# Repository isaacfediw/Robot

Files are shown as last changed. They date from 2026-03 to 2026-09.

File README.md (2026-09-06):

# Robot
A robot I am building that will follow you around

## Modes
### Auto Mode
**Overview**  
In auto mode the robot is designed to track the position of the transmitter and go to it.  
The DWM3000 can provide highly accurate and precise measurements when done correctly. The  
method I used for finding the distance between the robot (receiver) and the transmitter is known as  
double-sided two-way ranging. After calculating the distance I apply a lowpass fir filter to it using  
a hamming window with 31 taps. Once the distance is calculated the robot pivots itself slightly to the  
left and measures the distance again. It takes note of when the distance is incrementing. If the distance  
starts to decrement after it has already been noticed to increment the robot knows that the position before  
the last slight left pivot must be when the receiver antenna is angled farthest away from the transmitter  
antenna. This works because the receiver antenna is mounted near the end of the robot chassis.  



The problem with my current setup is that my distance measurements are not precise nor accurate when the  
receiver is mounted on the robot chassis. This is because the DWM3000 antennas are vertically polarized,  
which means they will communicate with the lowest amount of noise when they are both on the XZ plane.  
Although slightly more noisy (with introduced nulls), if both antenna are positioned on the XY plane,  
perpendicular to each other, the measurements are still relatively accurate and precise. For the time  
being (while in their respective chassis), the transmitter antenna is positioned on the XY plane and the  
receiver antenna is positioned on the YZ plane. This makes the measurements significantly inaccurate and  
imprecise, preventing auto mode from correctly working. My hope is to redesign the robot chassis to   
support ideally an antenna which is positioned on the XY plane but at the least on a 45 degree angle  
between the XY and YZ planes.  

**How double-sided two-way ranging works**  
6 timestamps are measured: t1 (measured when the transmitter  
sends the first frame), t2 (measured when the receiver receives that first frame), t3  
(measured when the receiver sends its first response), t4 (measured when the transmitter  
receives the receiver's first response), t5 (measured when the transmitter sends the second  
frame), and t6 (measured when the receiver receives that second frame).  

From the 6 timestamps, 4 time values are calculated. The round trip time for the first frame,  
the round trip time for the second frame, the reply time for the first frame, and the reply  
time for the second frame. The time of flight (tof) then calculated as:  
(round trip 1 * round trip 2 - reply 1 * reply 2) / (round trip 1 + round trip 2 + reply 1 + reply 2)  

<details> 
  <summary> For the proof on why the tof equation works click here </summary>

### DS-TWR Time-of-Flight Derivation
#### 1. Numerator Expansion:
$$
\begin{aligned}
\mathrm{tof\_num} &= R_1 R_2 - D_1 D_2 \\
&= (2T + D_1)(2T + D_2) - D_1 D_2 \\
&= 4T^2 + 2T D_2 + 2T D_1 + D_1 D_2 - D_1 D_2 \\
&= 4T^2 + 2T(D_1 + D_2) \\
&= 2T(2T + D_1 + D_2)
\end{aligned}
$$

#### 2. Denominator Expansion:
$$
\begin{aligned}
\mathrm{tof\_denom} &= R_1 + R_2 + D_1 + D_2 \\
&= (2T + D_1) + (2T + D_2) + D_1 + D_2 \\
&= 4T + 2D_1 + 2D_2 \\
&= 2(2T + D_1 + D_2)
\end{aligned}
$$

#### 3. Final Division and Cancellation:
$$
\begin{aligned}
\text{tof} &= \frac{\mathrm{tof\_num}}{\mathrm{tof\_denom}} \\
&= \frac{2T(2T + D_1 + D_2)}{2(2T + D_1 + D_2)} \\
&= \frac{2T}{2} \\
&= T
\end{aligned}
$$

</details>

We then multiply the time of flight by 15.65E-12 to get from DWT system time to seconds.  
Finally, to calculate the distance (in cm) the tof in seconds is multiplied by 100 times  
times the speed of light.  

### Manual Mode
**Overview**  
In manual mode the user has full control over the robot by using the joystick on the transmitter.  
The RP2040-Zero features a 12 bit adc, but I limit the range to 0 to 800 and then shift it by  
540 to make the rest position 0, the low position -240, and the highest position +260, in both  
x and y directions. I implemented a software deadzone of 50 adc values to prevent unwanted drifting  
when in manual mode.  
  
**How the direction and speed is decided**  
I compare the x and y adc value. If x > y then we want to turn the robot, otherwise we want to move  
forward or backward. If we are turning and x > 0 we want to go left, otherwise we go right. If we are  
not turning and y > 0 we want to go forwards, otherwise we go backwards. The amount of steps we want the  
robot to take is calculated by mapping the adc value to a steps value, using -240 and +260 as the adc range    
and 10 and 100 as the step range. This information is then sent to the robot in 3 bytes. (0xAB to indicate  
manual mode, a direction byte, and the number of steps as the final byte).  



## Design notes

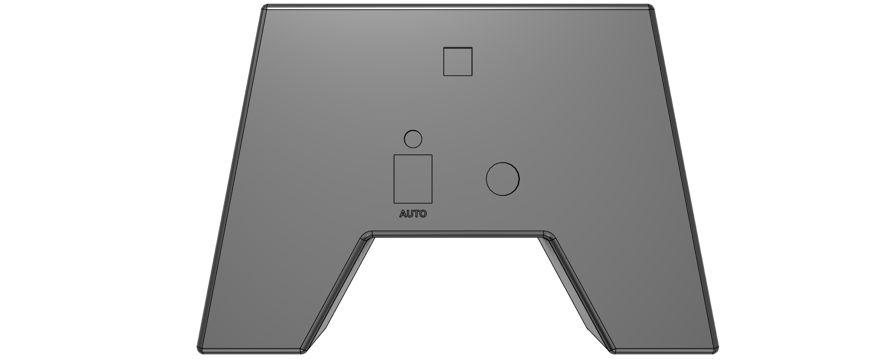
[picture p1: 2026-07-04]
Transmitter Schematic/Transmitter.png

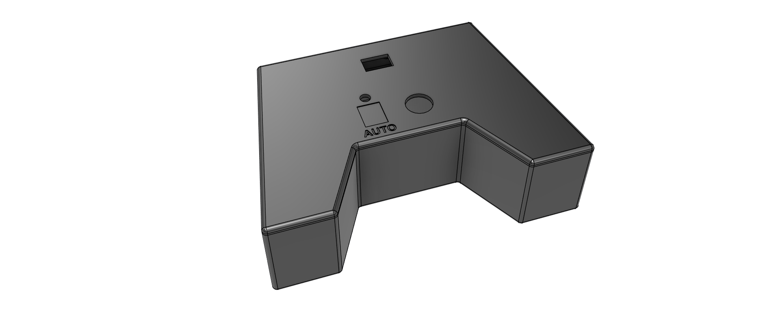
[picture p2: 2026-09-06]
3D Models/Transmitter/Transmitter 3D Model Image.png

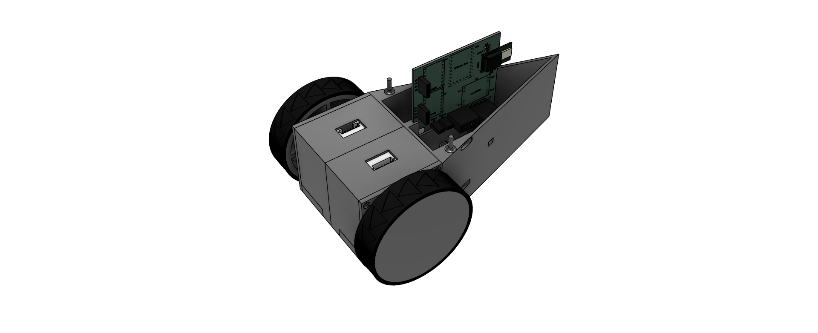
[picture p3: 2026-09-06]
3D Models/Robot/Robot 3D Model Image.png

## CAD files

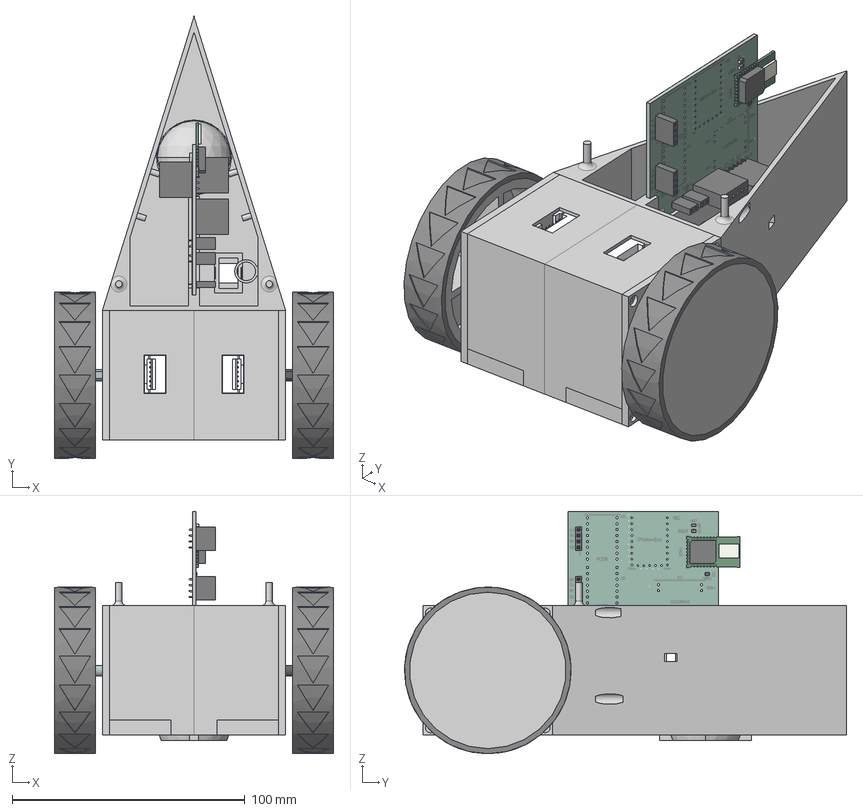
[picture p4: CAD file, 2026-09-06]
3D Models/Robot/Robot.step
120.0 x 190.0 x 104.2 mm
NEMA 17 (Check wire connector dimensions as well as shaft dimensions
Robot Left
Robot Right
NEMA 17 (Check wire connector dimensions as well as shaft dimensions( Mirror)
PinSocket_1x04_P2.54mm_Vertical x 2
C_0805_2012Metric x 2
R_0805_2012Metric
PinSocket_1x06_P2.54mm_Vertical x 2
DWM1000
PinSocket_1x02_P2.54mm_Vertical x 2
Robot_silkscreen
Robot_soldermask
Robot_soldermask_1
Robot_PCB
PinSocket_1x06_P2.54mm_Vertical_1

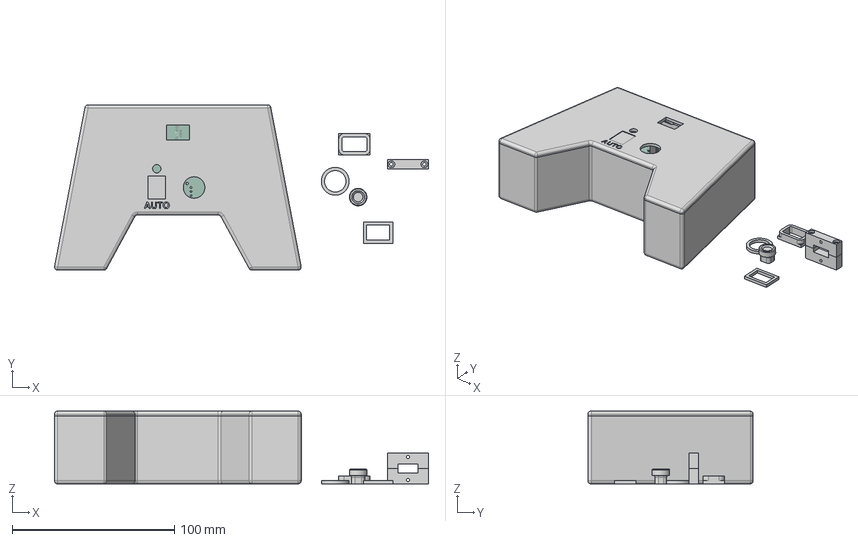
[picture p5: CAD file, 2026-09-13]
3D Models/Transmitter/Transmitter.step
230.6 x 102.0 x 45.0 mm
C_0805_2012Metric x 2
PinSocket_1x02_P2.54mm_Vertical x 4
R_0805_2012Metric x 2
PinSocket_1x03_P2.54mm_Vertical
DWM1000
Transmitter_silkscreen
Transmitter_soldermask
Transmitter_soldermask_1
Transmitter_PCB

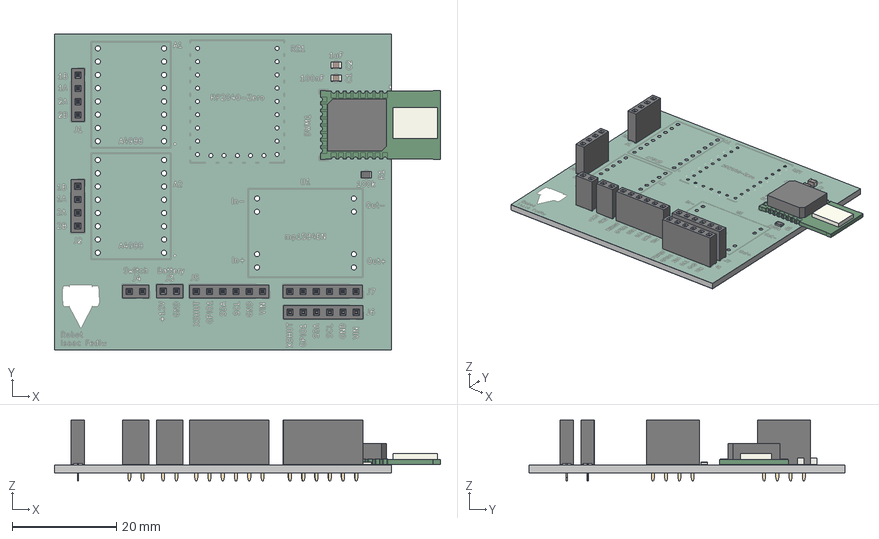
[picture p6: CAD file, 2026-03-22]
Robot Schematic/Robot PCB.step
73.9 x 60.6 x 11.6 mm
PinSocket_1x04_P2.54mm_Vertical x 2
C_0805_2012Metric x 2
R_0805_2012Metric
PinSocket_1x06_P2.54mm_Vertical x 3
DWM1000
PinSocket_1x02_P2.54mm_Vertical x 2
Robot_silkscreen
Robot_soldermask x 2
Robot_PCB

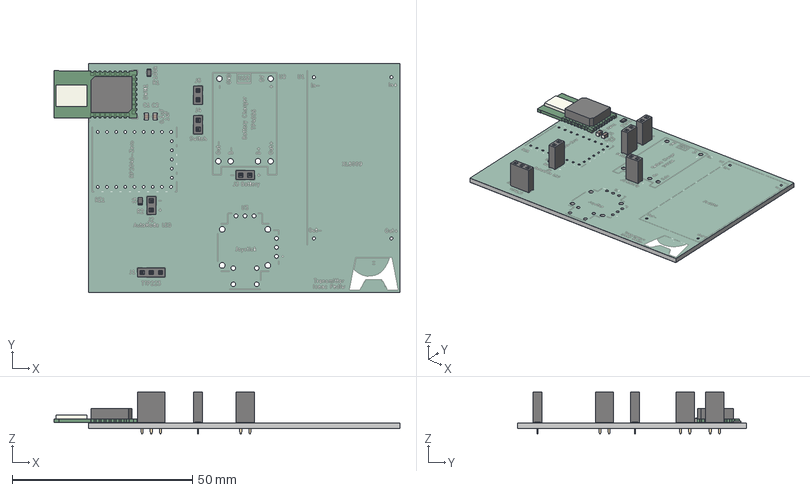
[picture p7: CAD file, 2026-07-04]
Transmitter Schematic/Transmitter.step
96.0 x 63.5 x 11.6 mm
C_0805_2012Metric x 2
PinSocket_1x02_P2.54mm_Vertical x 4
R_0805_2012Metric x 2
PinSocket_1x03_P2.54mm_Vertical
DWM1000
Transmitter_silkscreen
Transmitter_soldermask x 2
Transmitter_PCB

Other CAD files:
3D Models/Robot/Robot.3mf
3D Models/Transmitter/Transmitter.3mf

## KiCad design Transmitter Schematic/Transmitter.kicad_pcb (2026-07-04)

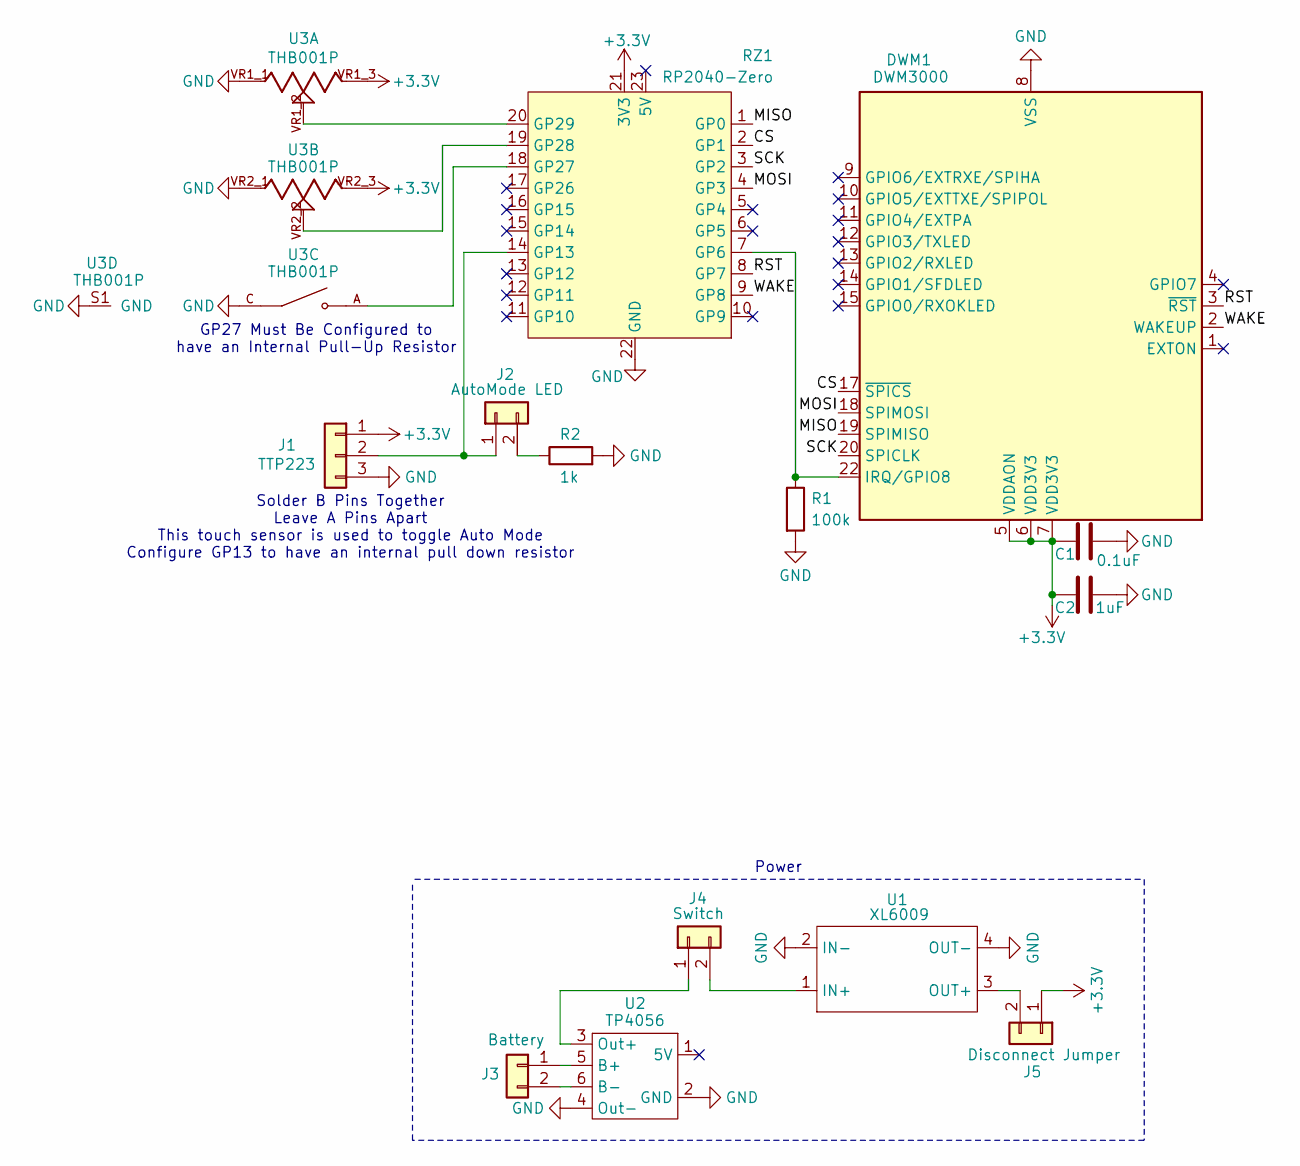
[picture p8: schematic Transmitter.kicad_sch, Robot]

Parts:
C1: 0.1uF; C_0805_2012Metric
C2: 1uF; C_0805_2012Metric
DWM1: DWM3000; DWM1000; MPN DWM3000.E1.1SR
J1: TTP223; PinSocket_1x03_P2.54mm_Vertical
J2: AutoMode LED; PinSocket_1x02_P2.54mm_Vertical
J3: Battery; PinSocket_1x02_P2.54mm_Vertical
J4: Switch; PinSocket_1x02_P2.54mm_Vertical
J5: Disconnect Jumper; PinSocket_1x02_P2.54mm_Vertical
R1: 100k; R_0805_2012Metric_Pad1.20x1.40mm_HandSolder
R2: 1k; R_0805_2012Metric_Pad1.20x1.40mm_HandSolder
RZ1: RP2040-Zero
U1: XL6009
U2: TP4056; TP4056-18650
U3: THB001P; CNK_THB001P; PARTREV 27 Jan 22

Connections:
+3.3V: C1.1, C2.1, DWM1.5 (VDDAON), DWM1.6 (VDD3V3), DWM1.7 (VDD3V3), J1.1, J5.1, RZ1.21 (3V3), U3.VR1_3, U3.VR2_3
/CS: DWM1.17 (~SPICS), RZ1.2 (GP1)
/MISO: DWM1.19 (SPIMISO), RZ1.1 (GP0)
/MOSI: DWM1.18 (SPIMOSI), RZ1.4 (GP3)
/RST: DWM1.3 (~RST), RZ1.8 (GP7)
/SCK: DWM1.20 (SPICLK), RZ1.3 (GP2)
/WAKE: DWM1.2 (WAKEUP), RZ1.9 (GP8)
GND: C1.2, C2.2, DWM1.8 (VSS), DWM1.16 (VSS), DWM1.21 (VSS), DWM1.23 (VSS), DWM1.24 (VSS), J1.3, R1.2, R2.2, RZ1.22 (GND), U1.2 (IN-), U1.4 (OUT-), U2.2 (GND), U2.4 (Out-), U3.C, U3.D, U3.S1 (GND), U3.S2, U3.S3, U3.S4, U3.VR1_1, U3.VR2_1
unnamed: DWM1.22 (IRQ/GPIO8), R1.1, RZ1.7 (GP6)
unnamed: J1.2, J2.1, RZ1.14 (GP13)
unnamed: J2.2, R2.1
unnamed: J3.1, U2.5 (B+)
unnamed: J3.2, U2.6 (B-)
unnamed: J4.1, U2.3 (Out+)
unnamed: J4.2, U1.1 (IN+)
unnamed: J5.2, U1.3 (OUT+)
unnamed: RZ1.18 (GP27), U3.A, U3.B
unnamed: RZ1.19 (GP28), U3.VR2_2
unnamed: RZ1.20 (GP29), U3.VR1_2

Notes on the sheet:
GP27 Must Be Configured to have an Internal Pull-Up Resistor
Power
Solder B Pins Together Leave A Pins Apart This touch sensor is used to toggle Auto Mode Configure GP13 to have an internal pull down resistor

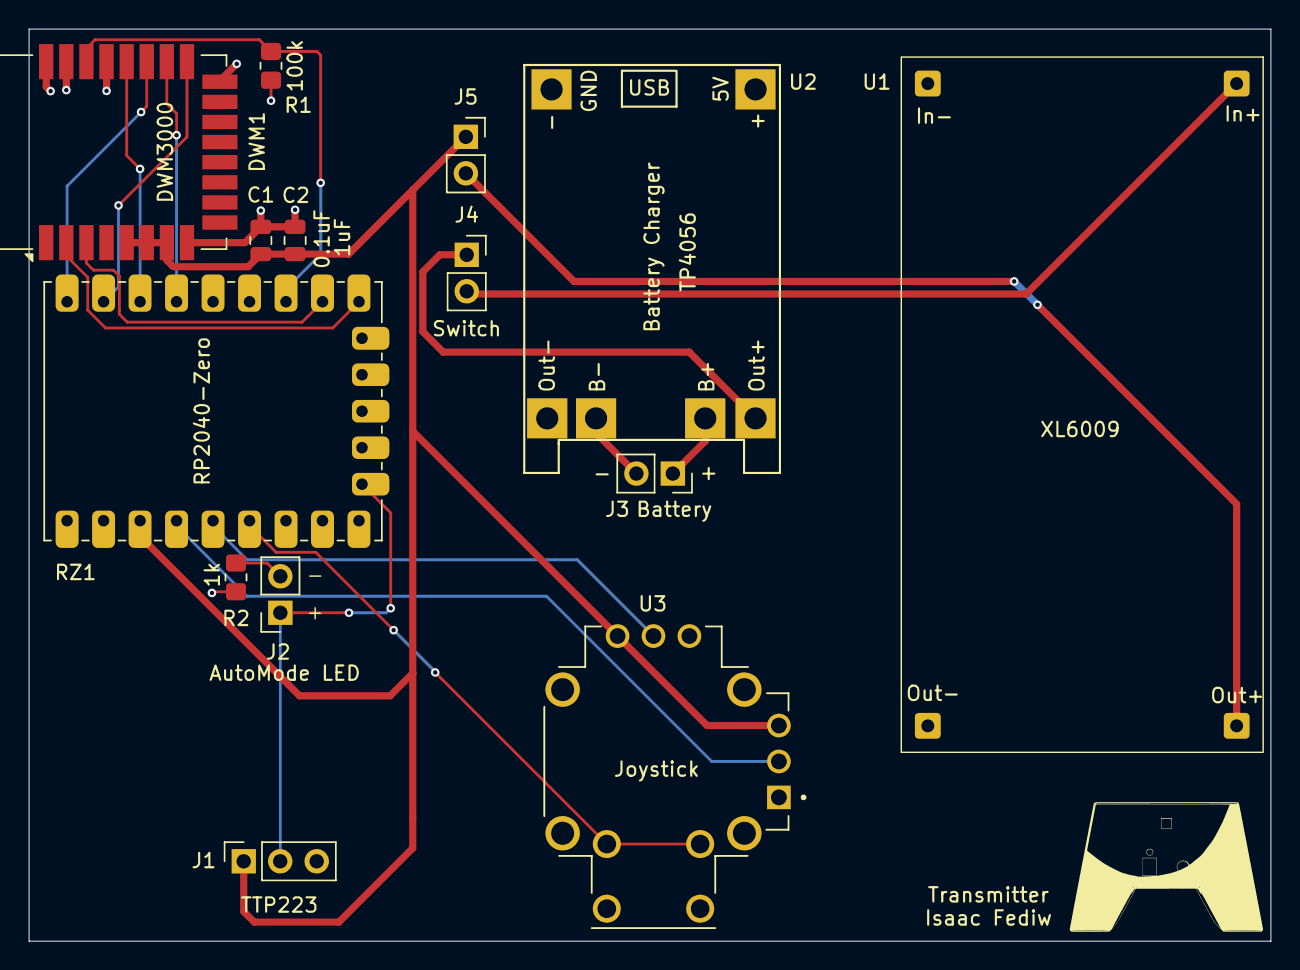
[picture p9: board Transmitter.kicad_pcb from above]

Board: 2 copper layers, 86.4 x 63.5 mm, 14 parts (0 on the bottom side), 19 nets.

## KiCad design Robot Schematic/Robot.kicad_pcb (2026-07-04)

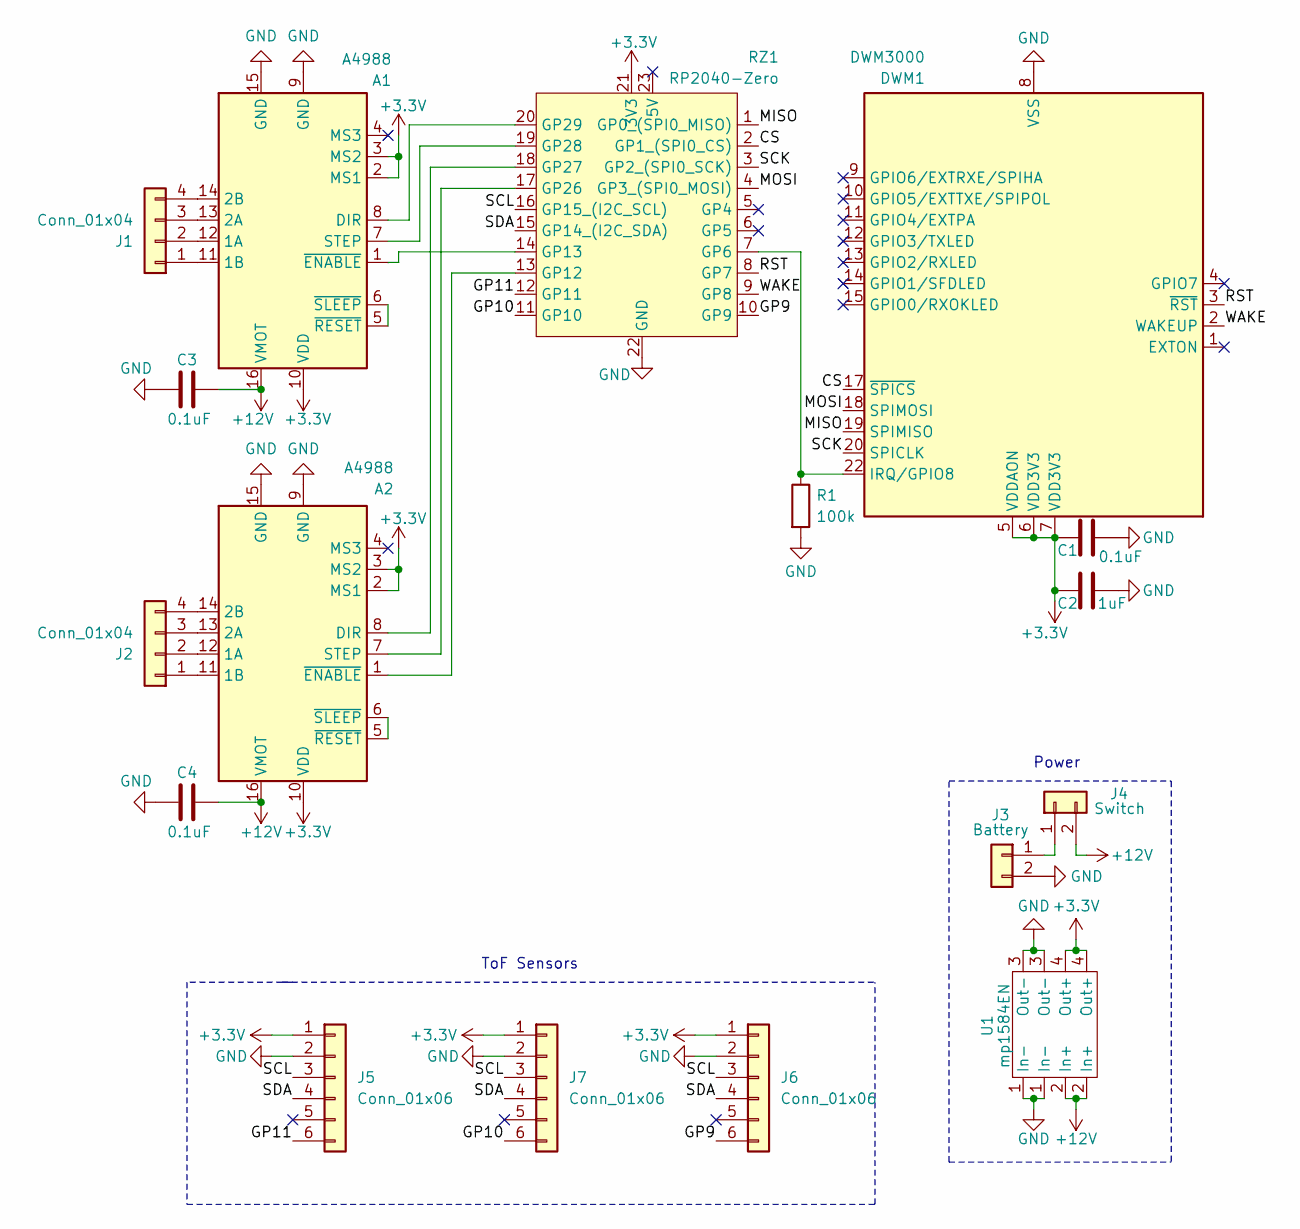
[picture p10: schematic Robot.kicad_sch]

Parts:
A1, A2: A4988
C1, C3, C4: 0.1uF; C_0805_2012Metric
C2: 1uF; C_0805_2012Metric
DWM1: DWM3000; DWM1000; MPN DWM3000.E1.1SR
J1, J2: Conn_01x04; PinSocket_1x04_P2.54mm_Vertical
J3: Battery; PinSocket_1x02_P2.54mm_Vertical
J4: Switch; PinSocket_1x02_P2.54mm_Vertical
J5, J6, J7: Conn_01x06; PinSocket_1x06_P2.54mm_Vertical
R1: 100k; R_0805_2012Metric_Pad1.20x1.40mm_HandSolder
RZ1: RP2040-Zero
U1: mp1584EN; mp158en

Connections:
+3.3V: A1.2 (MS1), A1.3 (MS2), A1.10 (VDD), A2.2 (MS1), A2.3 (MS2), A2.10 (VDD), C1.1, C2.1, DWM1.5 (VDDAON), DWM1.6 (VDD3V3), DWM1.7 (VDD3V3), J5.1, J6.1, J7.1, RZ1.21 (3V3), U1.4 (Out+)
+12V: A1.16 (VMOT), A2.16 (VMOT), C3.1, C4.1, J4.2, U1.2 (In+)
/CS: DWM1.17 (~SPICS), RZ1.2 (GP1_(SPI0_CS))
/GP9: J6.6, RZ1.10 (GP9)
/GP10: J7.6, RZ1.11 (GP10)
/GP11: J5.6, RZ1.12 (GP11)
/MISO: DWM1.19 (SPIMISO), RZ1.1 (GP0_(SPI0_MISO))
/MOSI: DWM1.18 (SPIMOSI), RZ1.4 (GP3_(SPI0_MOSI))
/RST: DWM1.3 (~RST), RZ1.8 (GP7)
/SCK: DWM1.20 (SPICLK), RZ1.3 (GP2_(SPI0_SCK))
/SCL: J5.3, J6.3, J7.3, RZ1.16 (GP15_(I2C_SCL))
/SDA: J5.4, J6.4, J7.4, RZ1.15 (GP14_(I2C_SDA))
/WAKE: DWM1.2 (WAKEUP), RZ1.9 (GP8)
GND: A1.9 (GND), A1.15 (GND), A2.9 (GND), A2.15 (GND), C1.2, C2.2, C3.2, C4.2, DWM1.8 (VSS), DWM1.16 (VSS), DWM1.21 (VSS), DWM1.23 (VSS), DWM1.24 (VSS), J3.2, J5.2, J6.2, J7.2, R1.2, RZ1.22 (GND), U1.1 (In-), U1.3 (Out-)
unnamed: A1.12 (1A), J1.2
unnamed: A1.11 (1B), J1.1
unnamed: A1.13 (2A), J1.3
unnamed: A1.14 (2B), J1.4
unnamed: A1.8 (DIR), RZ1.20 (GP29)
unnamed: A1.7 (STEP), RZ1.19 (GP28)
unnamed: A1.1 (~ENABLE), RZ1.14 (GP13)
unnamed: A1.5 (~RESET), A1.6 (~SLEEP)
unnamed: A2.12 (1A), J2.2
unnamed: A2.11 (1B), J2.1
unnamed: A2.13 (2A), J2.3
unnamed: A2.14 (2B), J2.4
unnamed: A2.8 (DIR), RZ1.18 (GP27)
unnamed: A2.7 (STEP), RZ1.17 (GP26)
unnamed: A2.1 (~ENABLE), RZ1.13 (GP12)
unnamed: A2.5 (~RESET), A2.6 (~SLEEP)
unnamed: DWM1.22 (IRQ/GPIO8), R1.1, RZ1.7 (GP6)
unnamed: J3.1, J4.1

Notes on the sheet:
Power
ToF Sensors

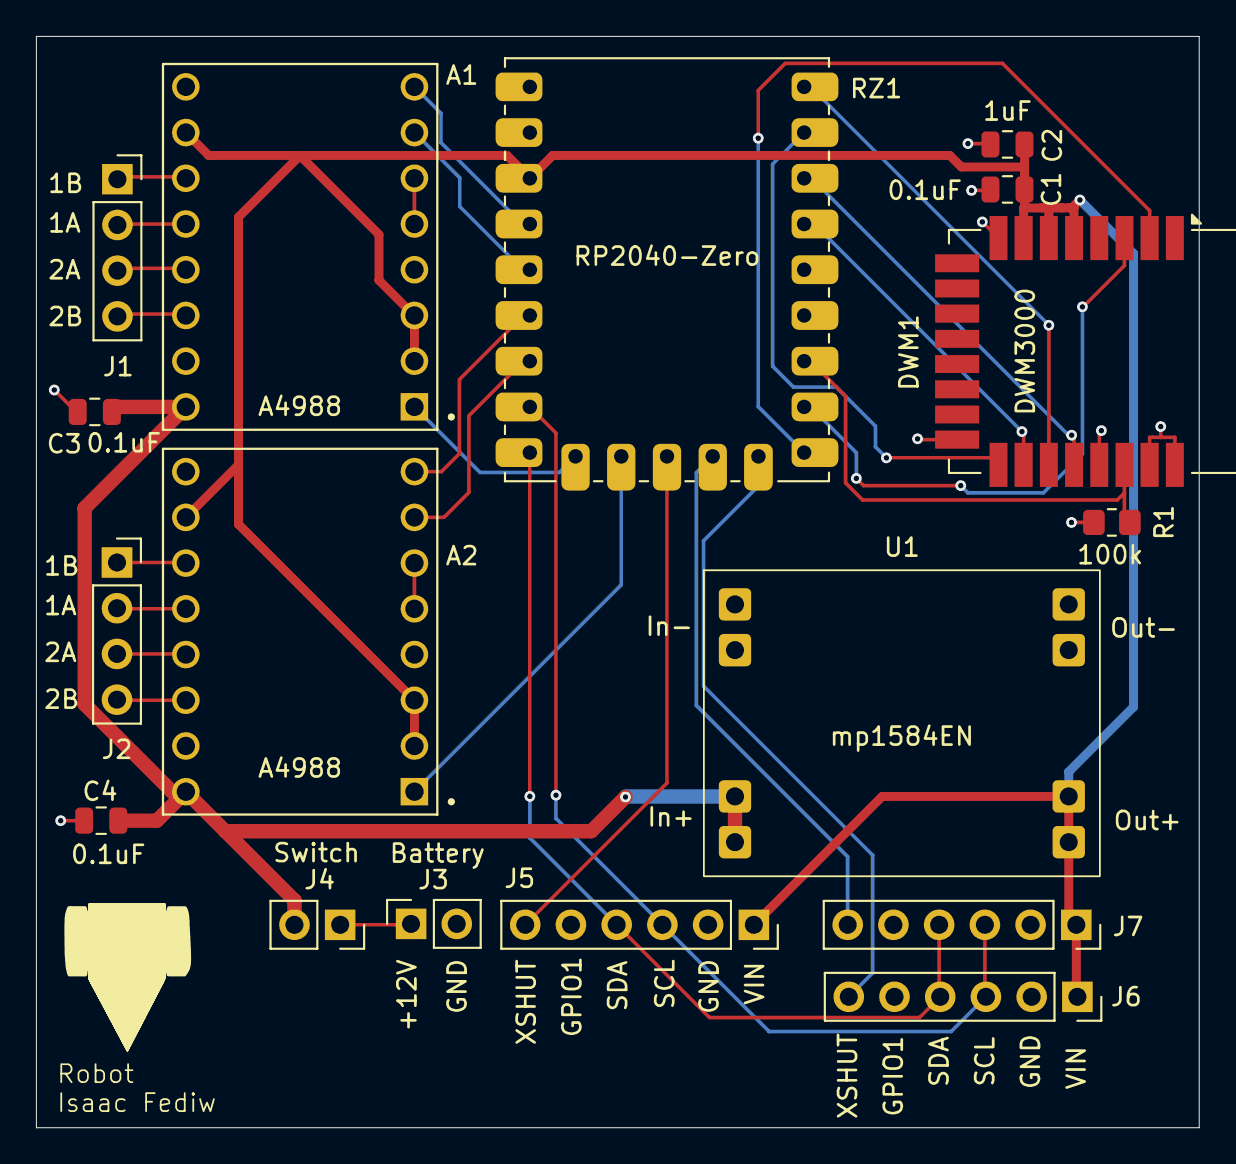
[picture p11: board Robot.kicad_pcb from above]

Board: 2 copper layers, 64.6 x 60.6 mm, 17 parts (0 on the bottom side), 32 nets.

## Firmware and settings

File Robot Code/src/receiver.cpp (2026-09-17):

#include <Arduino.h>
#include <SPI.h>
#include <vector>

#include "dw3000.h"
#include "Adafruit_VL53L0X.h"
#include "stepper.h"

#include "perlin_noise_walking.cpp"


// define statements
// dwm3000 definitions
#define PIN_IRQ 6
#define PIN_RST 7
#define PIN_WAKE 8

#define DWM_ID 0xDECA0302

#define MASK_40BIT 0x00FFFFFFFFFF

#define RECEIVER_ADDRESS    0x00000001
#define TRANSMITTER_ADDRESS 0x00000002

#define TX_ANT_DLY 16351
#define RX_ANT_DLY 16351

// #define TX_ANT_DLY 16385
// #define RX_ANT_DLY 16385

#define POLL_TX_TO_RESP_RX_DLY_UUS 600

#define NLOS_THRESHOLD_DB 6.0f // Threshold in dBm; values > 6.0 indicate an obstructed path

// spi definitions
#define SCK 2
#define MISO 0
#define MOSI 3
#define CS 1
#define SPI_CLK_SPEED 2000000

// i2c definitions
#define SCL 15
#define SDA 14
#define TOF1_ADDR    0x30
#define TOF2_ADDR    0x31
#define TOF3_ADDR    0x32

// tof definitions
#define TOF1_XSHUT 11 // front
#define TOF2_XSHUT 10 // right
#define TOF3_XSHUT 9  // left

#define TOF1_OFFSET 0 //20
#define TOF2_OFFSET 29
#define TOF3_OFFSET 52

#define OUT_OF_RANGE -20.0f
#define TOO_CLOSE 50 // 50 mm

// distance definitions
#define LENGTH 31
#define UPSAMPLE_FACTOR 4

// stepper definitions
#define LEFT_STEPPER_FORWARD   1
#define LEFT_STEPPER_BACKWARD  0
#define RIGHT_STEPPER_FORWARD  0
#define RIGHT_STEPPER_BACKWARD 1

#define MIN_RANDOM_MODE_STEPS  20
#define MAX_RANDOM_MODE_STEPS  100

// left stepper
#define DIR1  29
#define STEP1 28
#define EN1   13

// right stepper
#define DIR2  27
#define STEP2 26
#define EN2   12


// function definitions
void resetDWM();
double convolve(float h[], double x[]) ;
void checkData();
double calculateDistance();
bool send(uint32_t dest_address, uint8_t data[], int data_size);
void moveSteppers(int left_steps, int right_steps);
float tofSensorDistance(uint8_t address);

void serviceSensorsNonBlocking();


// global variables
int leftPins[3] = {STEP1, DIR1, EN1};
int rightPins[3] = {STEP2, DIR2, EN2};
stepper leftStepper(leftPins);
stepper rightStepper(rightPins);

Adafruit_VL53L0X tof1 = Adafruit_VL53L0X();
Adafruit_VL53L0X tof2 = Adafruit_VL53L0X();
Adafruit_VL53L0X tof3 = Adafruit_VL53L0X();

std::vector<int> dirs; // directions vector for random mode
StepperNoiseDriver driver;

enum class STATES {INITIAL, MOVING, FINISH};
STATES STATE;

uint64_t t1;
uint64_t t2;
uint64_t t3;
uint64_t t4;
uint64_t t5;
uint64_t t6;

double x[LENGTH];

float h[LENGTH] = { 
    1.6583E-03,1.9273E-03,1.8793E-03,7.1205E-04,-2.4593E-03,-7.7846E-03,
    -1.3926E-02,-1.7847E-02,-1.5438E-02,-2.9032E-03,2.1541E-02,5.6360E-02,
    9.6409E-02,1.3395E-01,1.6071E-01,1.7042E-01,1.6071E-01,1.3395E-01,
    9.6409E-02,5.6360E-02,2.1541E-02,-2.9032E-03,-1.5438E-02,-1.7847E-02,
    -1.3926E-02,-7.7846E-03,-2.4593E-03,7.1205E-04,1.8793E-03,1.9273E-03,
    1.6583E-03
};

volatile bool uwb_irq = false;

extern dwt_txconfig_t txconfig_options;

dwt_config_t config = {
    5,
    DWT_PLEN_1024,
    DWT_PAC32,
    9,
    9,
    1,
    DWT_BR_6M8,
    DWT_PHRMODE_STD,
    DWT_PHRRATE_STD,
    (1025 + 8 - 32),
    DWT_STS_MODE_OFF,
    DWT_STS_LEN_64,
    DWT_PDOA_M0
};


// function implementations
void dwm3000_isr() {
  uwb_irq = true;
}

void setup() {
    // serial monitor initialization
    Serial.begin(115200);

    uint32_t start = millis();
    while (!Serial && (millis() - start < 3000));
    delay(5);

    // spi initialization
    SPI.setSCK(SCK);
    SPI.setTX(MOSI);
    SPI.setRX(MISO);

    pinMode(CS, OUTPUT);
    digitalWrite(CS, HIGH);

    // dwm3000 initialization
    resetDWM();

    spiBegin(PIN_IRQ, PIN_RST);
    spiSelect(CS);

    delay(2);
    
    dwt_softreset();
    delay(2);

    while(!dwt_checkidlerc()) delay(10);

    if (dwt_initialise(DWT_DW_INIT) == DWT_ERROR) {
        Serial.println("Could not initialize API");
        while (1);
    }

    if (dwt_configure(&config) == DWT_ERROR) {
        Serial.println("Could not configure device");
        while (1);
    }

    uint32_t dev_id = dwt_readdevid();
    if (dev_id != DWM_ID) {
        Serial.println("Incorrect device ID");
        while (1);
    }

    dwt_configuretxrf(&txconfig_options);

    dwt_setrxantennadelay(RX_ANT_DLY);
    dwt_settxantennadelay(TX_ANT_DLY);

    dwt_setrxaftertxdelay(POLL_TX_TO_RESP_RX_DLY_UUS);

    // setup interrupts
    dwt_setinterrupt(DWT_INT_RX, 0, DWT_ENABLE_INT_ONLY);

     // note that the pin_irq is already set up as an input in spiBegin()
    attachInterrupt(digitalPinToInterrupt(PIN_IRQ), dwm3000_isr, RISING);

    STATE = STATES::INITIAL;

    for (int i = 0; i < LENGTH; i++) {
        x[i] = 0;
    }

    // IT IS VITAL THAT TOF INITIALIZATION HAPPENS AFTER DWM INITIALIZATION
    // tof sensor initialization
    pinMode(TOF1_XSHUT, OUTPUT);
    pinMode(TOF2_XSHUT, OUTPUT);
    pinMode(TOF3_XSHUT, OUTPUT);

    // assign addresses to TOF Sensors
    digitalWrite(TOF1_XSHUT, 0);
    digitalWrite(TOF2_XSHUT, 0);
    digitalWrite(TOF3_XSHUT, 0);
    delay(10);

    Wire1.setSDA(SDA); 
    Wire1.setSCL(SCL);
    Wire1.begin();

    digitalWrite(TOF1_XSHUT, 1);
    delay(10);
    if (!tof1.begin(TOF1_ADDR, false, &Wire1)) {
        Serial.println(F("Failed to boot Sensor 1"));
    }
    tof1.setMeasurementTimingBudgetMicroSeconds(33000);

    digitalWrite(TOF2_XSHUT, 1);
    delay(10);
    if (!tof2.begin(TOF2_ADDR, false, &Wire1)) {
        Serial.println(F("Failed to boot Sensor 2"));
    }
    tof2.setMeasurementTimingBudgetMicroSeconds(33000);

    digitalWrite(TOF3_XSHUT, 1);
    delay(10);
    if (!tof3.begin(TOF3_ADDR, false, &Wire1)) {
        Serial.println(F("Failed to boot Sensor 3"));
    }
    tof3.setMeasurementTimingBudgetMicroSeconds(33000);

    Serial.println(F("Booted sensors ready!"));


    dwt_rxenable(DWT_START_RX_IMMEDIATE);
    Serial.println("All initialization complete (receiver)");
}

void loop() {
    if (uwb_irq) checkData();
}

void checkData() {
    Serial.println("Checking data");
    delayMicroseconds(20);

    uwb_irq = false;

    uint32_t status = dwt_read32bitreg(SYS_STATUS_ID);

    if (!(status & SYS_STATUS_RXFCG_BIT_MASK)) {
        dwt_write32bitreg(SYS_STATUS_ID, SYS_STATUS_ALL_RX_TO | SYS_STATUS_ALL_RX_ERR);
        dwt_rxenable(DWT_START_RX_IMMEDIATE);
        return;
    }

    dwt_write32bitreg(SYS_STATUS_ID, SYS_STATUS_RXFCG_BIT_MASK);

    uint32_t rx_finfo = dwt_read32bitreg(RX_FINFO_ID);
    uint16_t rx_len = (uint16_t) (rx_finfo & RX_FINFO_RXFLEN_BIT_MASK) - 2;

    if (rx_len < 5 || rx_len > 64) {
        dwt_rxenable(DWT_START_RX_IMMEDIATE);
        return;
    }
    
    uint8_t rx_data[64];
    dwt_readrxdata(rx_data, rx_len, 0);

    uint32_t address;
    memcpy(&address, &rx_data[0], 4);

    if (address != RECEIVER_ADDRESS) {
        //Serial.println("Address is not that of the receiever");
        dwt_rxenable(DWT_START_RX_IMMEDIATE);
        return;
    }
    
    uint8_t data[1];
    double distance;
    
    int left_steps, right_steps;

    float left_sensor_distance, right_sensor_distance;
    bool left_clear, right_clear;

    int choice;

    Serial.printf("Received header 0x%X\n", rx_data[4]);

    switch (rx_data[4]) {
        case 0xAB: // manual mode header

            memcpy(&left_steps, &rx_data[5], 1);
            memcpy(&right_steps, &rx_data[7], 1);

            if (rx_data[6]  == 0x00) left_steps = -left_steps;
            if (rx_data[8] == 0x00) right_steps = -right_steps;

            moveSteppers(left_steps, right_steps);
            dwt_rxenable(DWT_START_RX_IMMEDIATE);

            break;
        case 0xAC: // random mode header
            /*// in this mode we just move the robot around randomly, accounting for obstacles using the tof sensors
            steps = random(MIN_RANDOM_MODE_STEPS, MAX_RANDOM_MODE_STEPS + 1);

            left_sensor_distance = tofSensorDistance(TOF3_ADDR);
            right_sensor_distance = tofSensorDistance(TOF2_ADDR);

            left_clear = left_sensor_distance == OUT_OF_RANGE || left_sensor_distance > TOO_CLOSE;
            right_clear = right_sensor_distance == OUT_OF_RANGE || right_sensor_distance > TOO_CLOSE;
            // also do same for forward when it's set up

            dirs.clear();

            // always valid till front sensor is added
            // going forward should have a higher chance so the robot actually moves with 'purpose'
            dirs.push_back(0);
            dirs.push_back(0);
            dirs.push_back(0);

            dirs.push_back(1); // always valid
            if (left_clear) dirs.push_back(2);
            if (right_clear) dirs.push_back(3);

            choice = dirs.at(random(0, dirs.size()));

            switch (choice) {
                case 0:
                    left_steps = steps;
                    right_steps = steps;
                    break;
                case 1:
                    left_steps = -steps;
                    right_steps = -steps;
                    break;
                case 2:
                    left_steps = -steps;
                    right_steps = steps;
                    break;
                case 3:
                    left_steps = steps;
                    right_steps = -steps;
                    break;
                default: break;
            }*/

            left_sensor_distance = tofSensorDistance(TOF3_ADDR);
            right_sensor_distance = tofSensorDistance(TOF2_ADDR);

            driver.update();

            left_steps = driver.left_steps;
            right_steps = driver.right_steps;

            // check if driver wants to go left
            if (left_steps < right_steps) {
                if (left_sensor_distance != OUT_OF_RANGE && left_sensor_distance <= TOO_CLOSE) {
                    left_steps *= -1;
                }
            // check if the driver wants to go right
            } else if (left_steps > right_steps) {
                if (right_sensor_distance != OUT_OF_RANGE && right_sensor_distance <= TOO_CLOSE) {
                    right_steps *= -1;
                }
            }

            moveSteppers(left_steps, right_steps);
            dwt_rxenable(DWT_START_RX_IMMEDIATE);
            
            break;
        case 0xFF:
            STATE = STATES::FINISH;
            //Serial.println("Received 0xFF");
            dwt_rxenable(DWT_START_RX_IMMEDIATE);
            
            break;
        case 0xAA:
            //Serial.println("Received 0xAA");

            // capture t2
            t2 = 0;
            uint8_t ts2[5];
            dwt_readrxtimestamp(ts2);
            memcpy(&t2, &ts2[0], 5);

            // respond and capture t3
            data[0] = 0x03;
            if (!send(TRANSMITTER_ADDRESS, data, 1)) {
                //Serial.println("Failed to send 0x03");
                dwt_rxenable(DWT_START_RX_IMMEDIATE);
                return;
            }

            t3 = 0;
            uint8_t ts3[5];
            dwt_readtxtimestamp(ts3);
            memcpy(&t3, &ts3[0], 5);

            break;
        case 0x15:
            if (rx_len < 20) {
                //Serial.println("Got 0x15 as a header but rx_len < 20");               
                dwt_rxenable(DWT_START_RX_IMMEDIATE);
                return;
            }

            //Serial.println("Received 0x15");

            t1 = 0;
            t4 = 0;
            t5 = 0;
            memcpy(&t1, &rx_data[5], 5);
            memcpy(&t4, &rx_data[10], 5);
            memcpy(&t5, &rx_data[15], 5);

            t6 = 0;
            // capture t6
            uint8_t ts6[5];
            dwt_readrxtimestamp(ts6);
            memcpy(&t6, &ts6[0], 5);

            distance = calculateDistance();

            // shift every input up by one and put distance into x[0]
            for (int i = LENGTH - 1; i > 0; i--) {
                x[i] = x[i - 1];
            }
            x[0] = distance;

            distance = convolve(h, x);
            
            Serial.printf("Distance: %.2fcm\n", distance);

            dwt_rxenable(DWT_START_RX_IMMEDIATE);

            break;
        default:
            //Serial.println("Did not get a header matching any valid options");
            dwt_rxenable(DWT_START_RX_IMMEDIATE);
    }
}

bool send(uint32_t dest_address, uint8_t data[], int data_size) {
    dwt_forcetrxoff(); // force into idle state. this is to prevent attempted transmitting while the receiver is enabled

    uint8_t tx_packet[4 + data_size];
    memcpy(&tx_packet[0], &dest_address, 4);

    for (int i = 0; i < data_size; i++) {
        tx_packet[4 + i] = data[i];
    }

    dwt_writetxdata(sizeof(tx_packet), tx_packet, 0);
    dwt_writetxfctrl(sizeof(tx_packet) + 2, 0, 0);

    bool complete = dwt_starttx(DWT_START_TX_IMMEDIATE | DWT_RESPONSE_EXPECTED) == DWT_SUCCESS;

    while (!(dwt_read32bitreg(SYS_STATUS_ID) & SYS_STATUS_TXFRS_BIT_MASK));

    delayMicroseconds(2); // just making sure that the dwm has enough time to re-enable it's receiver before I clear the bit
    dwt_write32bitreg(SYS_STATUS_ID, SYS_STATUS_TXFRS_BIT_MASK);

    return complete;
}

double calculateDistance() {
    int64_t round_trip_d1 = (int64_t) ((t4 - t1) & MASK_40BIT); 
    int64_t reply_d1 = (int64_t) ((t3 - t2) & MASK_40BIT);
    
    int64_t round_trip_d2 = (int64_t) ((t6 - t3) & MASK_40BIT);
    int64_t reply_d2 = (int64_t) ((t5 - t4) & MASK_40BIT);

    int64_t tof_num = round_trip_d1 * round_trip_d2 - reply_d1 * reply_d2;
    int64_t tof_denom = round_trip_d1 + round_trip_d2 + reply_d1 + reply_d2;

    double tof = (double) tof_num / (double) tof_denom;
    double tof_seconds = tof * DWT_TIME_UNITS;

    return tof_seconds * SPEED_OF_LIGHT * 100;
}

// moves both steppers (not just a scheduler)
// put steps negative to be backwards, postive for forwards
void moveSteppers(int left_steps, int right_steps) {
    Serial.printf("left_steps: %d, right_steps: %d\n", left_steps, right_steps);

    int left_dir = left_steps < 0 ? LEFT_STEPPER_BACKWARD : LEFT_STEPPER_FORWARD;
    int right_dir = right_steps < 0 ? RIGHT_STEPPER_BACKWARD : RIGHT_STEPPER_FORWARD;

    leftStepper.moveStepper(left_dir, abs(left_steps));        
    rightStepper.moveStepper(right_dir, abs(right_steps));  

    while (leftStepper.isBusy() || rightStepper.isBusy()) {
        leftStepper.stepperLoop();
        rightStepper.stepperLoop();
    }
}

float tofSensorDistance(uint8_t address) {
    VL53L0X_RangingMeasurementData_t measure;
    uint16_t offset = 0;
    bool applyAngleCorrection = false;

    switch (address) {
        case TOF1_ADDR:
            tof1.rangingTest(&measure, false);
            offset = TOF1_OFFSET;
            break;
        case TOF2_ADDR:
            tof2.rangingTest(&measure, false);
            offset = TOF2_OFFSET;
            applyAngleCorrection = true;
            break;
        case TOF3_ADDR:
            tof3.rangingTest(&measure, false);
            offset = TOF3_OFFSET;
            applyAngleCorrection = true;
            break;
        default: break;
    }

    // if it's out of range sometimes it gives the status, other times it measures 8191 but this is consistant behaviour
    if (measure.RangeStatus != 4 && measure.RangeMilliMeter != 8191) { // 4 means distance is out of range
        int16_t final_calculated_dist = (int16_t) (measure.RangeMilliMeter - offset);

        if (applyAngleCorrection) {
            final_calculated_dist *= 0.9548f; // cos(17.3 deg)
        }

        Serial.printf("Distance: %d mm\n", final_calculated_dist);
        return final_calculated_dist;
    } else {
        Serial.print("Out of range\n");
        return OUT_OF_RANGE;
    }
}

double convolve(float h[], double x[]) {
    double y = 0;

    for (int i = 0; i <= LENGTH - 1; i++) {
        y += x[i]*h[i]; // x is already shifted by the fact that we put new data into the array every cycle
    }

    return y;
}

void resetDWM() {
    pinMode(PIN_RST, OUTPUT);
    digitalWrite(PIN_RST, LOW);
    delay(10);
    digitalWrite(PIN_RST, HIGH);
    delay(20);
}


enum TofState { IDLE, MEASURING };
TofState tof_state = IDLE;
unsigned long tof_timer = 0;
float left_sensor_distance, right_sensor_distance;

void serviceSensorsNonBlocking() {
    switch (tof_state) {
        case IDLE:
            // 1. Kick off measurement without waiting in a while-loop
            tof2.startRangeContinuous();
            tof3.startRangeContinuous();
            
            tof_timer = millis();
            tof_state = MEASURING;
            break;

        case MEASURING:
            // 2. Allow RP2040 CPU to process UWB interrupts for 35ms
            if (millis() - tof_timer >= 35) {
                // 3. Read results non-blockingly
                if (tof3.isRangeComplete()) {
                    left_sensor_distance = tofSensorDistance(TOF3_ADDR);
                }
                if (tof2.isRangeComplete()) {
                    right_sensor_distance = tofSensorDistance(TOF2_ADDR);
                }

                // 4. Put sensors back into idle state
                tof2.stopRangeContinuous();
                tof3.stopRangeContinuous();
                
                tof_state = IDLE;
            }
            break;
    }
}

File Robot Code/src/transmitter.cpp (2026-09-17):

#include <Arduino.h>
#include <SPI.h>
#include <Adafruit_NeoPixel.h>

#include "dw3000.h"

extern "C" {
    void dwt_readsystime(uint8_t *timestamp);
}


// define statements
// on board led
#define ON_BOARD_LED 16
#define NUM_PIXELS   1

// joystick definitions
#define JOY_Y    29
#define JOY_X    28
#define JOY_SW   27 // give this an internal pull-up resistor
#define SW_DELAY 500

#define UPPER_ADC_VALUE 483  // adjusted for resting_pos of 540
#define LOWER_ADC_VALUE -507 // adjusted for resting_pos of 540
#define JOY_DEADZONE    50
#define RESTING_POS     540 

#define MAX_STEPS       100
#define MIN_STEPS       -100

// dwm3000 definitions
#define PIN_IRQ 6
#define PIN_RST 7
#define PIN_WAKE 8

#define DWM_ID 0xDECA0302

#define RECEIVER_ADDRESS    0x00000001
#define TRANSMITTER_ADDRESS 0x00000002

#define TX_ANT_DLY 16351
#define RX_ANT_DLY 16351

// #define TX_ANT_DLY 16385
// #define RX_ANT_DLY 16385

#define POLL_TX_TO_RESP_RX_DLY_UUS 600
#define RESP_RX_TIMEOUT_UUS 4000

// spi definitions
#define SCK  2
#define MISO 0
#define MOSI 3
#define CS   1
#define SPI_CLK_SPEED 2000000

#define AUTO 13


// function definitions
void resetDWM();
void checkData();
bool send(uint32_t dest_address, uint8_t  data[], int data_size, bool expect_response = true);
void manualControl();

// global variables
uint64_t t1;
uint64_t t4;
uint64_t t5;

bool initiated = false;
bool randomMode = false;
volatile bool uwb_irq = false;

uint64_t buttonStart;

Adafruit_NeoPixel pixel(NUM_PIXELS, ON_BOARD_LED, NEO_GRB + NEO_KHZ800);

extern dwt_txconfig_t txconfig_options;

dwt_config_t config =  {
    5,
    DWT_PLEN_1024,
    DWT_PAC32,
    9,
    9,
    1,
    DWT_BR_6M8,
    DWT_PHRMODE_STD,
    DWT_PHRRATE_STD,
    (1025 + 8 - 32),
    DWT_STS_MODE_OFF,
    DWT_STS_LEN_64,
    DWT_PDOA_M0
};


// function definitions
void dwm3000_isr() {
  uwb_irq = true;
}

void setup() {
    // serial monitor initialization
    Serial.begin(115200);

    uint32_t start = millis();
    while (!Serial && (millis() - start < 3000));
    delay(5);

    // spi initialization
    SPI.setSCK(SCK);
    SPI.setTX(MOSI);
    SPI.setRX(MISO);

    pinMode(CS, OUTPUT);
    digitalWrite(CS, HIGH);

    // joystick initialization
    pinMode(JOY_X, INPUT);
    pinMode(JOY_Y, INPUT);
    pinMode(JOY_SW, INPUT_PULLUP);

    buttonStart = millis();

    // auto button initialization
    pinMode(AUTO, INPUT_PULLDOWN);

    // neo-pixel initialization
    pixel.begin();

    // dwm3000 initialization
    resetDWM();

    spiBegin(PIN_IRQ, PIN_RST); 
    spiSelect(CS);

    delay(2);
    
    dwt_softreset();
    delay(2);

    while(!dwt_checkidlerc()) delay(10);

    if (dwt_initialise(DWT_DW_INIT) == DWT_ERROR) {
        Serial.println("Could not initialize API");
        while (1);
    }

    if (dwt_configure(&config) == DWT_ERROR) {
        Serial.println("Could not configure device");
        while (1);
    }

    uint32_t dev_id = dwt_readdevid();
    if (dev_id != DWM_ID) {
        Serial.println("Incorrect device ID");
        while (1);
    }

    dwt_configuretxrf(&txconfig_options);

    dwt_setrxantennadelay(RX_ANT_DLY);
    dwt_settxantennadelay(TX_ANT_DLY);

    dwt_setrxaftertxdelay(POLL_TX_TO_RESP_RX_DLY_UUS);
    dwt_setrxtimeout(RESP_RX_TIMEOUT_UUS);

    // setup interrupts
    dwt_setinterrupt(DWT_INT_RX, 0, DWT_ENABLE_INT_ONLY);

    // note that the pin_irq is already set up as an input in spiBegin()
    attachInterrupt(digitalPinToInterrupt(PIN_IRQ), dwm3000_isr, RISING);

    Serial.println("All initialization complete (transmitter)");
}

void loop() {
    if (!digitalRead(AUTO) && initiated) {
        uint8_t data[1] = {0xFF};
        send(RECEIVER_ADDRESS, data, 1, false);

        pixel.setPixelColor(0, pixel.Color(0, 0, 0));
        pixel.show();

        Serial.println("Sent 0xFF");

        initiated = false;
    } else if (digitalRead(AUTO) && !initiated) {
        uint8_t data[1] = {0xAA};
        if (send(RECEIVER_ADDRESS, data, 1)) {
            initiated = true;

            t1 = 0;
            // capture t1
            uint8_t ts1[5];
            dwt_readtxtimestamp(ts1);
            memcpy(&t1, &ts1[0], 5);

            //Serial.println("Sent 0xAA");
        } else {
            //Serial.println("Failed to send 0xAA");
        }
    } else if (!digitalRead(JOY_SW)) { // active low
        if (millis() - buttonStart >= SW_DELAY) {
            buttonStart = millis();

            randomMode = !randomMode;

            pixel.setPixelColor(0, pixel.Color(0, randomMode ? 255 : 0, 0));
            pixel.show();
        }
    }

    // auto mode
    if (digitalRead(AUTO) && uwb_irq && initiated) {
        uwb_irq = false;

        // this checks if bit 17 is set in SYS_STATUS register
        // bit 17 marks if the interrupt event was caused by receive wait timeout
        // if this receiver timed out it means we didn't get a packet from the robot
        // so we will need to send 0xAA again to start up the loop again
        // the result of this should appear as a seamless loop to the user
        uint32_t sys_status = dwt_read32bitreg(SYS_STATUS_ID);

        if (sys_status & SYS_STATUS_RXFTO_BIT_MASK) {
            dwt_write32bitreg(SYS_STATUS_ID, sys_status & SYS_STATUS_RXFTO_BIT_MASK);
            initiated = false;
        } else checkData();

    // manual mode
    } else if (!digitalRead(AUTO) && !randomMode) {
        manualControl();
    } else if (randomMode) {
        uint8_t data[1] = {0xAC};
        send(RECEIVER_ADDRESS, data, 1, false);
    }
}
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

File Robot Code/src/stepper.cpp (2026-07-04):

#include "stepper.h"
#include <Arduino.h>

#define STEP 0
#define DIR  1
#define EN   2

#define BASE_STEP_INTERVAL 1000 // slowest step interval

stepper::stepper(int stepper_pins[3]) {
    start = micros();
    lastStepMicros = 0; 
    stepState = false;
    busy = false;

    for (int i = 0; i < 3; i++) {
        pins[i] = stepper_pins[i];
        pinMode(pins[i], OUTPUT);
    }
}

void stepper::moveStepper(int dir, int steps) {
    if (busy) return;

    digitalWrite(pins[DIR], dir);
    digitalWrite(pins[EN], 0);
    stepsRemaining = steps * 8;

    acceleration = (int) ((float) BASE_STEP_INTERVAL / (float) (stepsRemaining/2 + 1));
    stepInterval = (acceleration > 0) ? BASE_STEP_INTERVAL : BASE_STEP_INTERVAL / 2;
    intervalDirection = -1;

    busy = true;
}

bool stepper::isBusy() {return busy;}

void stepper::stepperLoop() {
    start = micros();
    if (start - lastStepMicros >= stepInterval) {
        lastStepMicros = micros();
        stepState = !stepState;

        if (stepsRemaining > 0) {
            digitalWrite(pins[STEP], stepState);

            if (!stepState) {
                stepsRemaining --;

                if (stepsRemaining <= 0) {
                    digitalWrite(pins[EN], 1);
                    busy = false;
                }
            }
        }
 
        if (stepState) {
            stepInterval = stepInterval + intervalDirection * acceleration;
            if (stepInterval <= 200 || stepInterval >= BASE_STEP_INTERVAL) intervalDirection *= -1;
        }   
    }
}

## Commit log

2026-07-04 Add DWM Code, Add Transmitter Schematic/PCB
    DWM Code features a new library that works and is tested with basic features
    [Acceleration Calculations.xlsx, Robot.kicad_pcb, Robot.kicad_sch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]
2026-08-12 Consistent tracking (Not pathfinding yet)
    When placed in a configuration so that the transmitter is to it's left and ahead and the robot is placed facing with its backend in the direction of the transmitter (but still straight, the transmitt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
2026-08-17 Pretty decent/precise measuring with good tracking algorithm
    Problems are that it still randomly loses connection sometimes
    [receiver.cpp, transmitter.cpp]
2026-08-19 Important Fixes (Timing on this version is perfect)
    [receiver.cpp, transmitter.cpp]
2026-08-26 Add filtering and infinite looping
2026-09-06 Update README with distance measurement issues and solutions
    Expanded on the limitations of the current setup and proposed redesign for improved accuracy.
2026-09-06 Add 3D Models
    [Robot.3mf, Transmitter.3mf]
2026-09-06 Add step files for 3D Models
    [Robot.step, Transmitter.step]
2026-09-13 Fix ToF + DWM Issue
    There was an issue that when the dwm code was running the tof sensors completely froze. This is fixed now by simply initializing the tof sensors after the dwm!
    [Transmitter.3mf, Transmitter.step]
2026-09-13 Preliminary random mode with perlin noise
    [receiver.cpp, transmitter.cpp]
2026-09-17 Add differential steering to manual mode
